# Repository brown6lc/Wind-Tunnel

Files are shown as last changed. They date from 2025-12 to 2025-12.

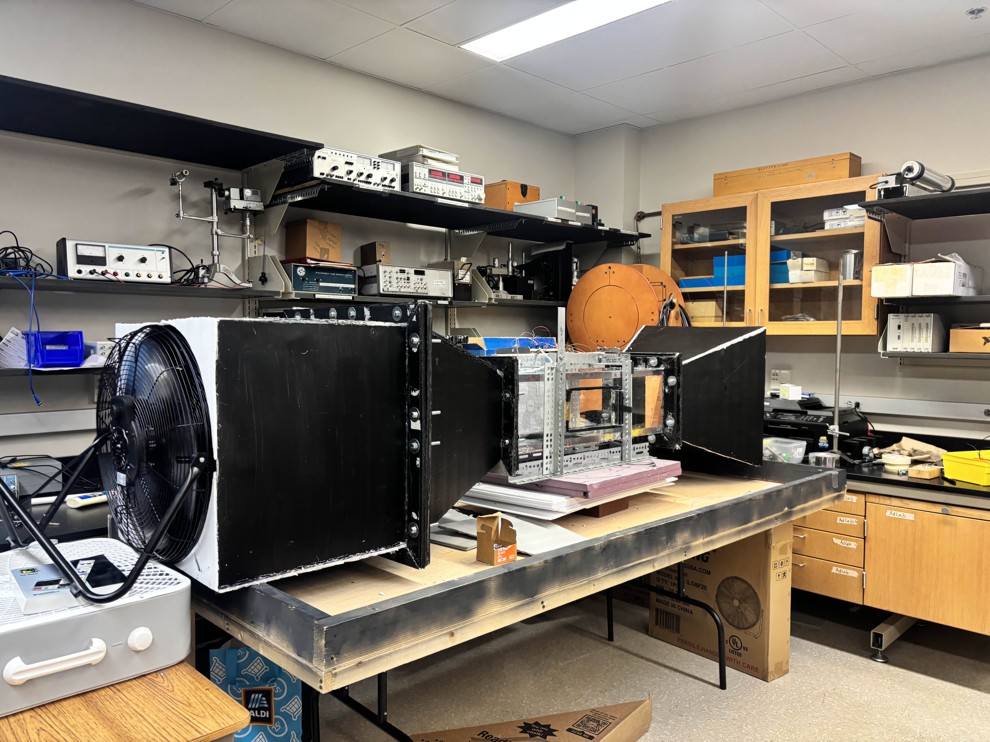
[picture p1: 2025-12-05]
windTunnel.jpg

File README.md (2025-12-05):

Wind Tunnel Senior Design Project
Mechanical Construction & Design Team
8-Foot Wind Tunnel System
Overview

This project was completed as part of the Senior Design course in the Applied Physics/Engineering
program. Our team was responsible for the mechanical construction and design of an 8-foot wind
tunnel intended for educational laboratory use and preliminary aerodynamic testing.
The objective was to design a structurally sound, modular, safe, and easily serviceable wind tunnel
capable of producing uniform, measurable airflow for experiments involving drag, lift, flow visualization,
and sensor calibration.

Project Goals
- Design and construct the mechanical body of an 8-ft wind tunnel.
- Ensure smooth airflow through proper test section geometry, contraction ratios, and diffuser design.
- Integrate mechanical systems with electrical components (fan, control system) designed by partner
teams.
- Prioritize safety, material accessibility, and long-term durability for repeated academic use.
  
Mechanical Design Responsibilities
Our group focused on all mechanical aspects, including:
1. Frame and Structural Design
- Designed a modular frame supporting the 8-ft tunnel body.
- Selected materials to balance rigidity, vibration damping, cost, and manufacturability.
- Considered thermal expansion, load distribution, and long-term fatigue.
2. Tunnel Body Construction
- Designed the test section, contraction cone, diffuser, and flow conditioning region.
- Chose materials such as acrylic, plywood, and aluminum depending on section requirements.
- Ensured proper alignment and sealing of all sections to minimize turbulence and leakage.
3. Flow Conditioning Components
- Implemented a honeycomb flow straightener and optional screen meshes.
- Designed mounting methods for consistent alignment and easy replacement.
4. Fan and Motor Integration
- Created mechanical interfaces for the fan housing, vibration isolation, and airflow coupling.
- Ensured safe clearances, mounting stability, and service access for the electrical/control team.
5. Assembly & Fabrication
- Oversaw machine shop workflows and fabrication scheduling.
- Constructed, assembled, and tested mechanical subsystems.
- Made iterative adjustments based on airflow tests and structural feedback.
  
Key Design Features
- 8-foot total length for stable airflow development.
- Transparent test section for visualization and measurement.
- Removable panels for maintenance and access.
- Vibration-isolated fan mount to reduce noise and flow disturbances.
- Modular section design enabling upgrades or experimental modifications.
  
Testing & Validation
The following tests were conducted during development:
- Smoke and fog flow visualization to assess turbulence.
- Static pressure measurements along the tunnel body.
- Velocity measurements in the test section using an anemometer/hot-wire probe.
- Mechanical vibration and leak testing.
- Fit-up checks of all joints and seals.
Findings from testing guided several refinements, such as improving sealing surfaces, reinforcing frame
attachment points, and adjusting the diffuser angle.

Team Contributions (Mechanical Subgroup)
- CAD modeling of all mechanical components (Fusion 360).
- Material selection and sourcing.
- Precision fabrication and machining.
- Mechanical assembly and troubleshooting.
- Documentation of assembly procedures and mechanical performance.
  
Acknowledgments
We thank the Senior Design instructors, machine shop staff, and collaborating electrical/control teams
for their support throughout the project.

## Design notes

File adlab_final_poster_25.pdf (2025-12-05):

# Advanced Physics Laboratory 2025 – Wind Tunnel Project

### Driver and Smoke Production

E. Bare, C. Beattie, L. Brown, T. Brown, L. Cressman, A. Ebner, J. Gann, A. Hardie, K. Lopez, S. Pearne, A. Pisarcik, C. Shick, F. Stover, and J. Veliz Diaz Supervisors: Jacob Brown, Maria Niculescu, and Gabriel Niculescu

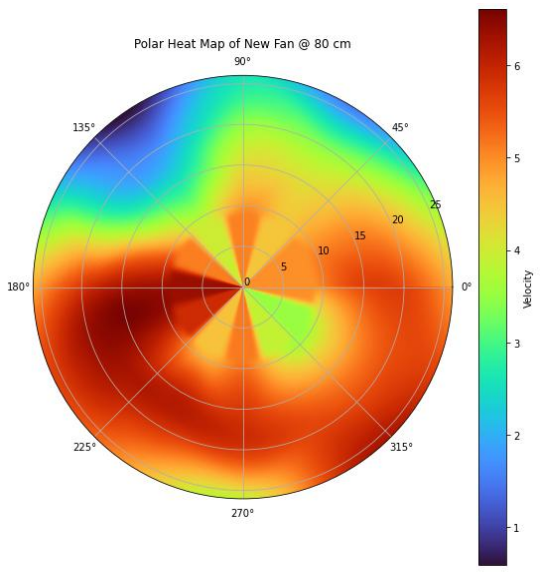
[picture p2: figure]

Figure 4: Polar Heat Map for Black Fan. Max Speed of 6.3 m/s.

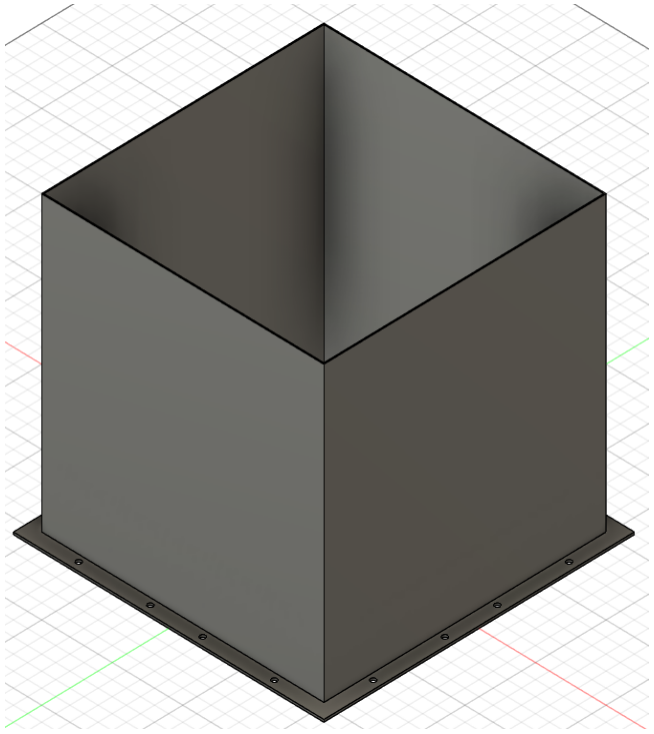
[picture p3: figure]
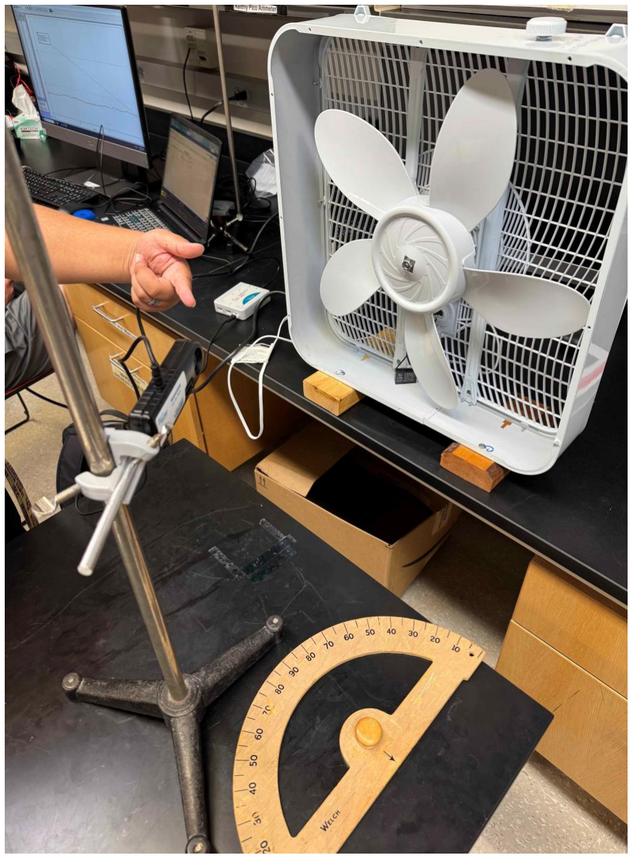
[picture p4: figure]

- While we originally wanted to use the white fan as shown in Figure 1, the wind speed was deemed too low to blow through the length of the wind tunnel.
- The black fan shown in Figure 3 proved to be an adequate replacement, although still not very uniform as shown in Figure 4.
- Smoke production proved harder than first expected. We first used the smoke machine shown in Figure 2, however the smoke produced was too thick and inconsistent.
- Another design included burning incense in a mason jar, and then pumping smoke out of the jar. This design proved too weak, and we ultimately fell back on using the smoke machine we first landed on.
- If we were to use the smoke machine, the wind tunnel as a whole will be physically constrained to being outside, near a snorkel, near a fume hood, or other ventilation systems.

Figure 3: Black Fan.

Figure 2: Smoke
Producing Machine

Figure 1: Obtaining Angle Data for White Fan.

## Testing Chamber

- Measured lift, drag, and wind speed with pressure sensor and force probes using the Arduino as an interpreter (a).
- Used python and Arduino code to graph data in real time (b).
- Attached pitot tubes to pressure sensor and arms to force probes to transfer movement from the air foil.

(a)

(c)

- Plexiglass chamber was built for combined maximum visibility and rigidity. J-B Weld epoxy and ducting tape were used to firmly attach the corners together (c).
- Stainless steel frame was made to house the chamber and the load bearing arms for the air foil (d).
- E387 air foil was 3d printed and inserted into the chamber for low wind speed testing.

Construction Process:
1. Modeled in Solid Works
2. Constructed wooden template to standardize layer dimensions
3. Used template to construct all 15 layers individually
4. Coated layers to alleviate imperfections
5. Attached all layers to create honey comb

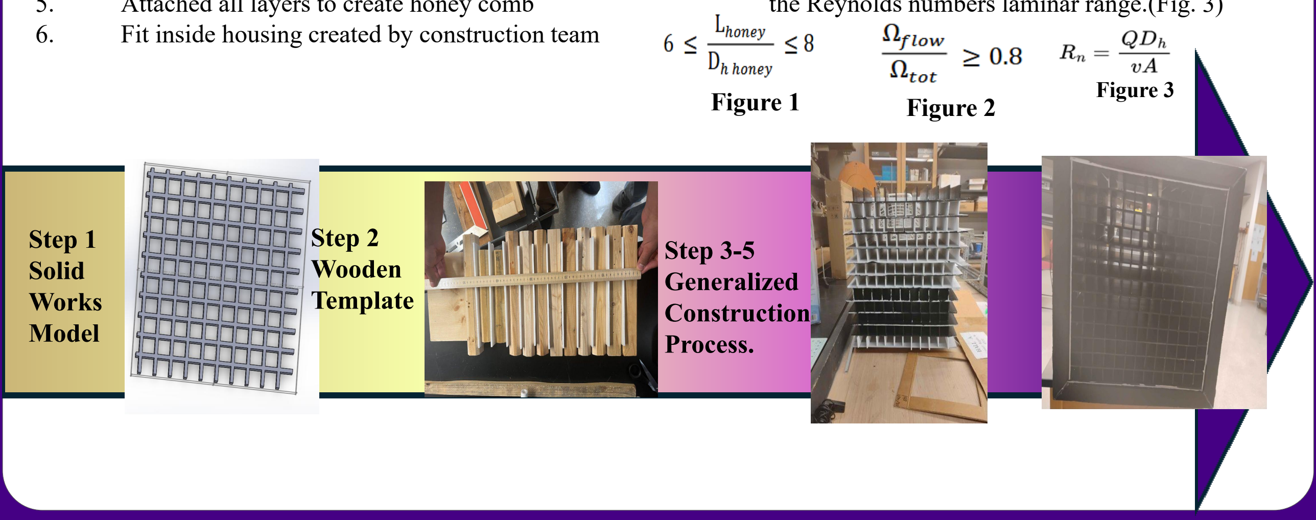
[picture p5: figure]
Step 1 Solid Works Model; Step 2 Wooden Template; Step 3-5 Generalized Construction Process.; Figure 3; Figure 1; Figure 2

6. Fit inside housing created by construction team

Key Design Factors:
- Ratio of honeycomb length to individual cell diameter should be between 6 and 8 (see Fig. 1)
- Surface porosity, or ratio of the cross-sectional area available for flow to the total cross sectional area (see Fig. 2)
- Both of these equations arise from manipulation of the Reynolds numbers laminar range.(Fig. 3)

## Honey Comb

Achieving laminar flow requires the construction of a honey comb to prevent the formation of eddies or turbulence

### Mechanical Design and Construction

Figure 1: Housing Chamber

Figure 2: Contraction Chamber

Construction:
- The housing chamber is created from four separate pieces of laminated bilayer EPS poster board secured by contact cement, with a 0.545x0.545 m cross section. The contraction chamber's dimensions are 0.545 x 0.545 m, narrowing to 0.25 x 0.25 m with a decline angle of 16.88°. The diffuser starts at 0.25 x 0.25 m and expands to 0.59 x 0.59 m with an incline of 19.55°. Flanges between chambers consist of four separate pieces of four layered EPS poster board, joined at mitered corners with hot glue.
- All pieces were painted with a 1:1 mixture of black acrylic paint and mod podge before assembly. Then, the panels for each chamber were assembled with a method detailed in our paper, pinned at a 90 degree angle, hot glued, and then trimmed to the correct size.
- After the chamber's body panels were glued together, the flanges were pinned to the ends of each chamber and hot glued, but the testing chamber flanges were only hot glued. The gap between the flange and the incline of the diffuser or contraction chamber were filled with hot glue to increase strength and prevent leakage.
- Finally, holes were drilled at 4 inches from each edge for the small flanges and 4 inches and 9 inches from each edge for the large flange using a 3/8" drill bit. 2.5 inch-long 3/8" hex head bolts were used to connect the flanges along with nuts and washers, a design that allows for the disassembly of the system into its separate parts.

Key Objectives:
- Develop robust, and repeatable construction methods with focus on flexibility and adaptability.

Materials:
- EPS foam board, contact cement, mod podge, black acrylic paint, hot glue, pins, and 3/8" bolts, nuts, and washers.

(b)

(d)

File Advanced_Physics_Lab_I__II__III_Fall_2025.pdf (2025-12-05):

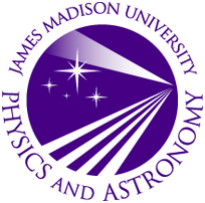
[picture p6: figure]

# Wind Tunnel Portion Report

# Mechanical and Construction Group

## Jakeline Veliz, Alex Hardie, Landon Brown

## Dr. Ioana Niculescu, Dr. Gabriel Niculescu

December 4, 2025

## 1 Abstract

The Mechanical and Construction (M&C) team was responsible for the construction of a housing chamber for the fan and honeycomb, diffuser, and contraction chamber of a low-speed wind tunnel targeting the 5 to 10 m/s wind speed mark—as determined by choice of fan—at approximately 2.5 meters length total. Several research articles and online textbooks were consulted to discover optimal parameters for preservation of flow uniformity such as settling chamber length, angles of depression for the diffuser and contraction chamber, and flange design. Other quantities, such as contraction ratio, were in part determined in a design document given by Drs. Niculescu. The M&C team prioritized adaptability to changing constraints—such as a change in fan or honeycomb dimensions—and developed construction methods with this in mind. Our findings have resulted in robust, repeatable construction methods that withstand the conditions of a typical, very low speed wind tunnel while achieving target geometries

## 2 Introduction

The flow source for this wind tunnel is a consumer grade floor fan. It is circular, and has a diameter of 0.545 meters. The fan is placed in the threshold of the intake of the settling chamber so that the lip running the circumference of the fan is directly outside of the back pressure reduction panels. The interior of the settling chamber consists of a honeycomb-style flow straightener whose cells are 0.05 m by 0.05 m to reduce swirl and turbulence in the air flow and to create a more uniform flow. The air then passes through the contraction chamber, which further contributes to a uniform flow and increases the flow in the testing chamber. The contraction reduces the total cross-sectional area to 0.25 m by 0.25 m. The testing chamber is a clear Plexiglass section with electronics implemented to measure wind speed, pressure, and other forces. Finally, the diffuser is mounted at the end of the testing chamber for pressure recovery and returns the cross-sectional area to 0.590 m by .590 m. The diffuser serves the opposite purpose as the contraction chamber, creating a gradual velocity reduction and pressure increase to minimize turbulence. Each piece is connected to the next via flanges, created from four layers of foam used to construct the main pieces of the wind tunnel. All panels are left straight, as to avoid the challenges of bending foam.

## 3 Mechanical Design and Construction

### 3.1 Cutting Foam

Cutting single-layer foam is simple, and its general process translates to multi-layer foam. When cutting foam, the team found that clean lines may be achieved through a process dubbed “score-and-snap,” in which a razor is gently guided through half of a given layer, then picked up and bent in the direction opposite of the score, then towards the direction of the score. This results in a distinctive “snap” and a clean, repeatable line that is generally difficult to achieve directly by cutting. For multilayer foam, one should seek to cut one layer at a time, using the cut to guide the blade as it goes deeper into the multilayer foam. After reaching the bottom layer, snap as above. With this method for cutting, the team was able to achieve a near-perfect success rate for desired geometries.

### 3.2 Laminating and Painting Foam

The most basic mechanical design element is the lamination of foam panels for the construction of the body of each chamber. To prepare for lamination, EPS foam boards—commonly used for school projects—are stripped of their paper backing by spraying them down with alcohol and gently peeling off the backing. Prepared panels may be done in two ways, depending on the needs of the project. The first method is for projects whose largest chamber length is longer than the width of the prepared panels, typically 50 cm for boards sourced from Dollar Tree. This method staggers bilayer foam such that the middle of any piece of foam is met by the end of another—that is, staggered like bricks. Staggering like this has the benefit of achieving longer panel lengths; however, the process of measuring to the middle of each foam board can introduce mounting error over time. This is especially true when one factors in that half-panels must also be cut to end this pattern. The M&C team frequently found that it resulted in misaligned panels, despite careful double measurements. Overall, this method should only be pursued if one desires longer chamber lengths. The second method, which we used for the team’s project, is direct lamination, in which one prepared panel is placed directly atop another. Both methods require the use of 3M 77 contact cement. The contact cement should be applied conservatively, and from a distance of at least 10 cm from the surface being sprayed, as excess contact cement will melt the EPS foam. The contact cement should be sprayed outside and on grass, so as not to damage facilities. Finally, the contact cement must be tacky prior to lamination, rather than still wet, and may be checked by placing one’s knuckles onto the sprayed adhesive. Following this procedure, we were able to rapidly create body panels that may be used in any element of construction.
After lamination, there remains the step to paint the laminated panels with a 1:1 mixture of modge podge and black acrylic paint. The amount necessary is minimal and should only be so much as to eliminate all striations on the prepared panel’s surface. The mod podge provides rigidity to the final construction and—though it is not understood why—typically makes the score-and-snap of cutting easier. This step is optional at this point, though highly recommended, as painting finished products is generally more difficult and space intensive.

### 3.3 Panel-to-Panel Connections

Prepared panels may be joined in a variety of ways, though the team has settled on one that is repeatable, easy, and offers non-permeant fastening for temporary alignment. To join a panel, the team first pins two panels together, normal with respect to one another with the pins contained entirely within the panels. Generally, many pins are needed, approximately one every 5 cm. After a panel is pinned and the team is ready to make a permanent bond, a bead of white glue is run between where the panels meet. This is allowed to sit to correct any topological defects in the panel. After approximately five minutes of dry time, a bead of hot glue is run over the white glue and allowed to dry completely. When fastening together laminated foam panels, one is generally joining them at 90° with respect to one another; however, this procedure works for angles more or less than normal (we used 70° without issue, though more hot glue is necessary to fill the gaps). The extrema of this tolerance have not been explored.

### 3.4 Honeycomb and Fan Housing Chamber

The honeycomb is an essential part of the wind tunnel—assuring that laminar flow is maintained by straightening the flow—and is placed inside the housing chamber. The honeycomb is friction-fit to the inside of the chamber and may be removed at any time due to the particularly laborious nature of its creation. Should anything happen to the settling chamber, then the honeycomb may be removed and repurposed. The honeycomb is made of 12 layers stacked vertically with an extra 13th layer placed on the side. The housing chamber was assembled by using prepared, painted direct-laminated 0.508 m × 0.762 m panels.

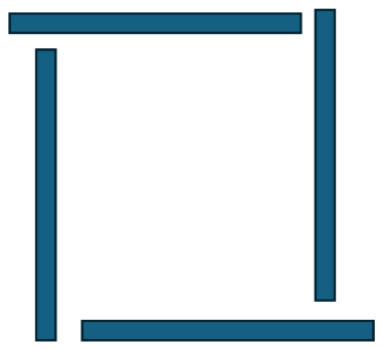
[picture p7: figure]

Figure 1: Staggered design of panels for housing chamber.

The panels are assembled in an offset square pattern, as seen in the figure above, and are then fastened in the standard method as described with pins, white glue, and hot glue. The bottom panel is placed onto a level surface, then the leftmost panel is attached with pins. Then, the two panels are flipped so that they are standing. The third panel is then pinned to the correct width to the bottom panel. After, the leftmost panel as shown above is then cut to the desired height after being rotated so that it is on a level surface, and the fourth panel is attached onto the freshly cut surface and pinned to the second and third panels. The interior of each panel is measured to ensure correct geometry and then the panels are permanently bonded as described above. Afterwards, the excess from each panel is removed with the standard score-and-snap. This construction method achieves a team goal of remaining adaptable, as it allows for one standard panel for any size fan, given the fan does not exceed 0.76 m in length. It achieves the desired geometry every time, as the height and width are bespoke to the fan. The results of which are below, in a CAD rendering.

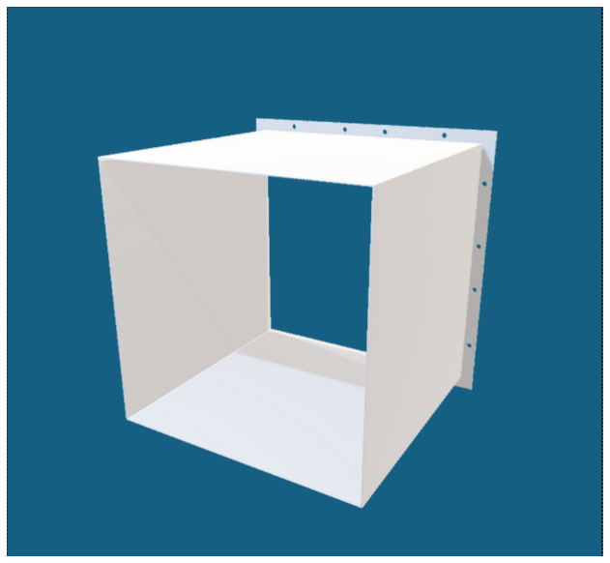
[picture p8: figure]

Figure 2: CAD rendering of housing chamber

### 3.5 Contraction Chamber

The contraction chamber follows the housing chamber with a gentle slope in order to preserve laminar flow while accelerating the air. The contraction chamber is constructed with prepared, bilayer foam panels using a method generalized from the construction of the housing chamber. For our contraction chamber, we were advised to optimize for space and disregard literature values of a 20° angle for the contraction chamber’s slope. We proceeded to construct these panels, then, without cutting to a specified width—which determines the angle of the contraction chamber. The key relationship here is that the angle of the contraction chamber’s slope, α, is determined by α = arcsin hfan−hTC
2Lpanel

, where the hi are the heights of the fan and testing chamber respectively (typically determined by experimental constraints), for a square cross section, and Lpanel is the length of the panel (determined by the construction team). Proceeding with the algebra depending on design specifications on either angle or panel length, one may determine remaining parameters. Note that for square cross-sections, the height and length are interchangable.

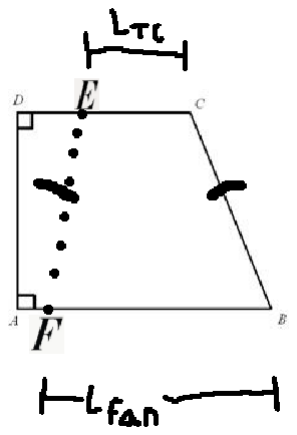
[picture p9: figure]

Figure 3: Rough sketch of geometry of contraction chamber panel

To start construction, take a prepared bilayer foam panel, and from one of the corners make a mark that is a distance of Lfan−LT C
2

on the edge of the side that will meet the testing chamber. Then, score-and-snap from that mark at point C to the corner at point B, resulting in the right trapezoid above. Now, place a mark on the line segment CD that is the length of the testing chamber away from point C—we will call this point E. We will then mark another point, point F, to be the length of the interior of the housing chamber (typically the length of the fan) from point B. A line is then drawn from this mark at point E to point F, resulting in the isosceles trapezoid EF BC of the correct dimension of our panel, without measuring an angle. This process is repeated three more times for each body panel. To assemble, take any CB, and place it outside of the line segment EF so that the edge of the panel is just outside of EF towards AD. Pin together as outlined above and repeat the process until construction is completed. Ensure correct interior dimensions prior to permanently bonding the surfaces with hot glue. This reliably yields a geometrically correct contraction chamber and can be easily completed in under 30 minutes. In the end, our panel length was 0.508 m, our angle of depression was 16.88 degrees, and our chamber length was 0.495 m. The result for the process is below, prior to trimming, on a prototype as well as the CAD rendering of the finished contraction chamber.

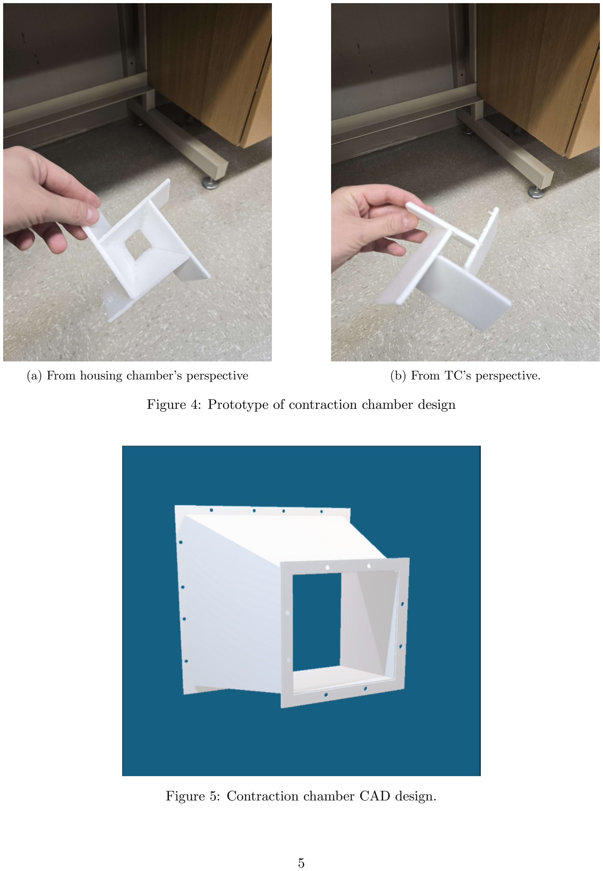
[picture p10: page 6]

(a) From housing chamber’s perspective | (b) From TC’s perspective.

Figure 4: Prototype of contraction chamber design

Figure 5: Contraction chamber CAD design.

### 3.6 Diffuser

The purpose of the diffuser is to gradually expand the flow area of the air from higher speed, lower pressure flow to a lower speed, higher pressure flow to minimize turbulence, and maintain steady airflow. The diffuser is at the end of the wind tunnel and its construction follows the exact same procedure as the contraction chamber, except no large flange is necessary for this piece. In our case, the chambers are slightly different, as we repurposed the intake from a previous iteration, so its angle of elevation is 19.55 degrees, its panel length is .508 m, and its total chamber length is 0.488 m. The literature states that the diffuser’s angle should be sharper than the contraction chamber’s so that the chamber may evacuate the air more quickly with a steeper angle (Hernandez et al., 2013); however, the team was given specific guidance to make these two parts exactly the same.

### 3.7 Structural Frame

Each part is attached to the next via a flange, made of four layers of the same foam used to construct the rest of the wind tunnel. Each flange is 0.05 m wide and consists of four pieces of laminated foam with their edges cut to 45 degrees to allow for a higher margin of error as far as measurement goes when constructing the parts. The large flanges, each piece about 0.55 m long, were pinned and hot glued to one end of the housing chamber and to the large end of the contraction chamber. First, four layers of foam were glued together with contact cement and cut at a 0.05 m width lengthwise, which gave the templates for the flanges.
The flanges were attached to each chamber by setting a chamber flat on a table, pinning the flanges in the position they needed to be in, and hot gluing the flanges to the chambers once they were in the proper position. Hot glue was used to fill the gap between the flange and the incline of the contraction and diffusion chambers. After the flanges were firmly attached to their respective chamber, flanges in contact with one another were clamped together and a 3/8” drill bit was used to create holes for the bolts that would attach each flange. A similar process was used for the small flanges, each measuring about 25 cm long, that attached the small end of the diffuser to the testing chamber and the other end of the testing chamber to the diffuser.
Our initial design for the flanges consisted of a hollow square cut from double-layered foam that was just a single piece. We found that this was too much of a constraint, since the measurement of the surrounding chambers was not cut precisely to what we expected. After discovering this, we decided that it would be best to change to a new design and only cut the flanges once all the other parts were complete. This allowed for more leniency as far as dimensions were concerned. In the final design, we also decided to use four layers of foam instead of the two layers in the initial design, which allowed more room to glue each part to the next. Another problem we had was fitting the corners of each flange together. If we could change this design, we would use a staggered square design similar to the design that we used for the housing chamber.

## 4 Conclusion

The construction of each piece and the integration into a single, functional wind tunnel system was ultimately a success. However, there were various areas that could be improved as far as construction went. One of the major oversights was creating a surface or some sort of support that accounted for the varying lengths of the separate parts of the wind tunnel, most notably was the large difference between the bottom of the large flange and the bottom of the testing chamber. To compensate for this, we stacked multiple layers of foam until the testing chamber was level with small flanges and, although this works as a temporary solution, there are more ideal ways to create a permanent solution such as attaching metal stands to the testing chamber. Finally, it is possible to adapt our construction method to curved forms, allowing for easy, replicable creations of something once thought to be very difficult. Overall, we have proven highly replicable, durable, adaptable, and precise methods for construction of a low-speed wind tunnel; however, several design decisions were made that will be likely hinder preservation of laminar flow, so further testing is needed to verify whether or not our wind tunnel can preserve or even create laminar flow.

## Works Cited

Hern´andez, Miguel A. Gonz´alez, et al. “Design Methodology for a Quick and Low-Cost Wind Tunnel.” Wind Tunnel Designs and Their Diverse Engineering Applications, IntechOpen, 6 Mar. 2013, https://doi.org/10.5772/54169.

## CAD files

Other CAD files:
Contraction Chamber.f3d
Diffuser.f3d
Flanges.f3d

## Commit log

2025-12-03 Added incomplete fusion 3D files
    Designs include contraction chamber, flanges, and the diffuser.
    [Contraction Chamber.f3d, Diffuser.f3d, Flanges.f3d]
2025-12-05 Added technical documentation
    This document describes the materials and methods used to construct each part of the wind tunnel.
2025-12-05 Update CAD software reference in README
